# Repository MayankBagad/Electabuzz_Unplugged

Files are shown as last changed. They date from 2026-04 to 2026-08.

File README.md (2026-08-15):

# 🚗 Electabuzz: Line Follower Robot Hardware Platform

> **A custom hardware design, PCB layout, sensor interface, and power system package for a line-following mobile robot platform.**

Developed by **Team Electrabuzz** for *UNPLUGGED — A 24-Hour Hardware Hackathon* organized by DJSCE × IETE-ISF × DJS MicroMinds VLSI Club.





---

## 📸 Project Overview

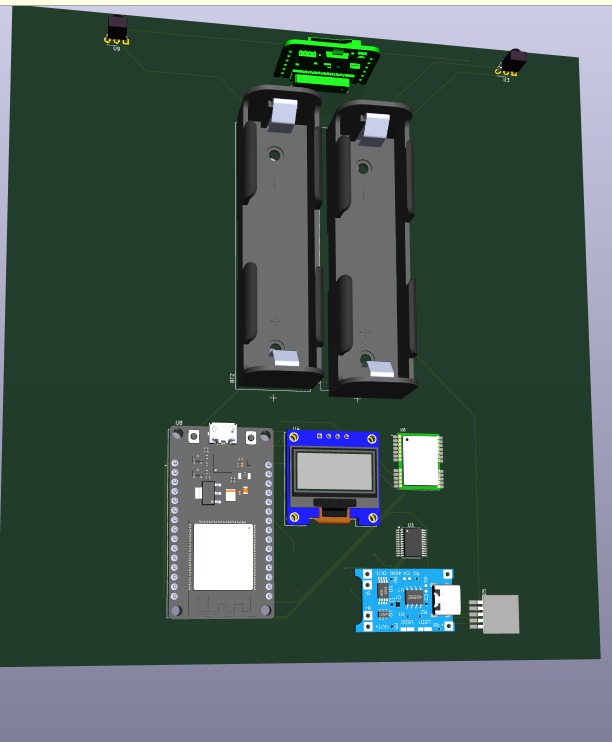
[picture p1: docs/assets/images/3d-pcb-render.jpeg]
3D PCB Render


---

## ⚡ Key Engineering Deliverables

- **Custom Form-Factor PCB**: 2-layer FR4 PCB designed in KiCad 9.0 to fit mechanical chassis boundaries, with separate ground returns for logic and motor circuits.
- **Integrated Sensor & Actuator Interface**: Onboard routing for an ESP32 microcontroller, 5-channel IR tracking array, TB6612FNG dual DC motor driver, 0.96" I²C OLED display, NEO-6M GPS, and ESP32-CAM module.
- **Dual-Domain Power Architecture**: Solar-assisted Li-ion battery charging (TP4056 + 2× 18650 cells) with LM2596 buck regulation for 5V/3.3V logic, alongside an isolated 12V motor supply rail.
- **Wide-Range Isolated Power Front-End (Simulation)**: LTSpice SPICE simulation of a $\pm 12\text{V}$ to $\pm 50\text{V}$ DC polarity-independent isolated flyback converter with logic-level polarity telemetry.
- **Design Verification**: Checked with KiCad Electrical Rules Check (ERC) and Design Rules Check (DRC).

---

## 🎯 Problem & Engineering Approach

### The Problem
Line-follower robots require clean sensor signal routing, reliable motor current delivery, and stable logic power. Connecting high-draw DC motors directly to the same unregulated battery rail as the microcontroller often causes voltage dips, electrical noise, and unwanted MCU resets.

### The Engineering Solution
**Electabuzz** addresses these requirements at the board level:
1. **Isolated Power Rails**: Logic circuitry (ESP32, sensors, OLED) is powered via an LM2596 buck regulator from 18650 Li-ion cells, while motors are driven through a dedicated 12V rail on the TB6612FNG driver.
2. **Consolidated Board Layout**: Integrates power management, compute, telemetry, and motor switching onto a single PCB shaped to match chassis mounting holes.
3. **Transient-Tolerant Power Simulation**: A supplementary flyback converter stage was modeled to evaluate polarity-independent operation and surge clamping under wide DC input ranges.

---

## 🏗 System Architecture

```
                              ┌───────────────────┐
                              │  6V Solar Panel   │
                              └─────────┬─────────┘
                                        │ (1N5819 Schottky Diode)
                                        ▼
 ┌──────────────────────┐     ┌───────────────────┐
 │ 2× 18650 Li-ion      │◄───►│  TP4056 Charger   │
 │ Battery (Parallel)   │     │ (Protection IC)   │
 └──────────────────────┘     └─────────┬─────────┘
                                        │ ~3.7V - 4.2V VBAT
                                        ▼
                              ┌───────────────────┐
                              │ LM2596 Buck Conv. │──► 5.0V Logic Rail (ESP32 VIN, CAM 5V)
                              └─────────┬─────────┘
                                        │
           ┌────────────────────────────┴────────────────────────────┐
           │                                                         │
           ▼                                                         ▼
 ┌───────────────────┐                                     ┌───────────────────┐
 │ ESP32-DEVKIT-V1   │◄────────────── UART0 ──────────────►│ ESP32-CAM (OV2640)│
 │ (Main Controller) │                                     └───────────────────┘
 └───┬───┬───┬───┬───┘
     │   │   │   │
     │   │   │   └─────────── I²C (GPIO 21/22) ───────────► 0.96" SSD1306 OLED (0x3C)
     │   │   └─────────────── UART2 (GPIO 16/17) ─────────► NEO-6M GPS Module
     │   └─────────────────── GPIO Inputs ────────────────► 5× IR Sensor Array
     │
     └─────────────────────── PWM / Direction ────────────► TB6612FNG Motor Driver
                                                                     │
                    (Dedicated 12V Motor Rail) ──────────────────────┼──► 2× 12V DC Motors
```

---

## 🔌 Hardware Interfaces & Pin Mapping

| ESP32 Pin | Connected Device | Pin / Function | Signal Type | Description |
|:---:|:---:|:---:|:---:|:---|
| **GPIO 25** | TB6612FNG | `AIN1` | Digital Out | Motor A Direction 1 |
| **GPIO 26** | TB6612FNG | `AIN2` | Digital Out | Motor A Direction 2 |
| **GPIO 27** | TB6612FNG | `PWMA` | PWM Out | Motor A Speed Control |
| **GPIO 14** | TB6612FNG | `BIN1` | Digital Out | Motor B Direction 1 |
| **GPIO 12** | TB6612FNG | `BIN2` | Digital Out | Motor B Direction 2 |
| **GPIO 13** | TB6612FNG | `PWMB` | PWM Out | Motor B Speed Control |
| **GPIO 32** | TB6612FNG | `STBY` | Digital Out | Driver Enable / Standby ($10\text{ k}\Omega$ pull-up) |
| **GPIO 21** | SSD1306 OLED | `SDA` | I²C Data | Display I²C Data line ($4.7\text{ k}\Omega$ pull-up) |
| **GPIO 22** | SSD1306 OLED | `SCL` | I²C Clock | Display I²C Clock line ($4.7\text{ k}\Omega$ pull-up) |
| **GPIO 16** | NEO-6M GPS | `TX` | UART RX2 | Serial GPS telemetry input |
| **GPIO 17** | NEO-6M GPS | `RX` | UART TX2 | Serial configuration output |
| **GPIO 34** | IR Sensor 1 | `OUT` | Digital In | Leftmost line sensor |
| **GPIO 35** | IR Sensor 2 | `OUT` | Digital In | Mid-left line sensor |
| **GPIO 36** | IR Sensor 3 | `OUT` | Digital In | Center line sensor |
| **GPIO 39** | IR Sensor 4 | `OUT` | Digital In | Mid-right line sensor |
| **GPIO 33** | IR Sensor 5 | `OUT` | Digital In | Rightmost line sensor |
| **GPIO 1** | ESP32-CAM | `U0RXD` | UART TX0 | Inter-module serial link |
| **GPIO 3** | ESP32-CAM | `U0TXD` | UART RX0 | Inter-module serial link |

> 📖 **Full Details**: For bus specifications and pinout notes, see [Architecture Documentation](docs/architecture.md).

---

## 🖥 PCB Design & Power Architecture

| Schematic Capture | Copper Layer Routing (Top & Bottom) |
|:---:|:---:|
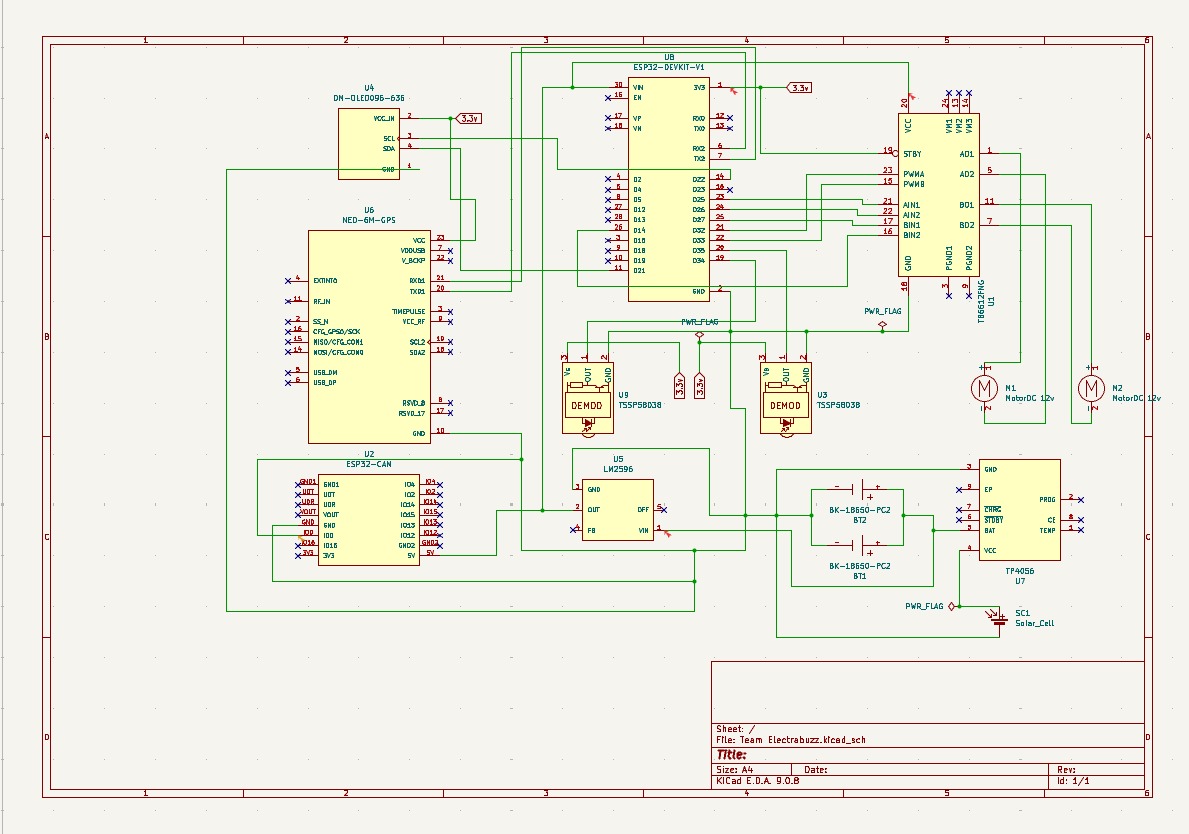
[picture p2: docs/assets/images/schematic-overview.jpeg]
Schematic Overview
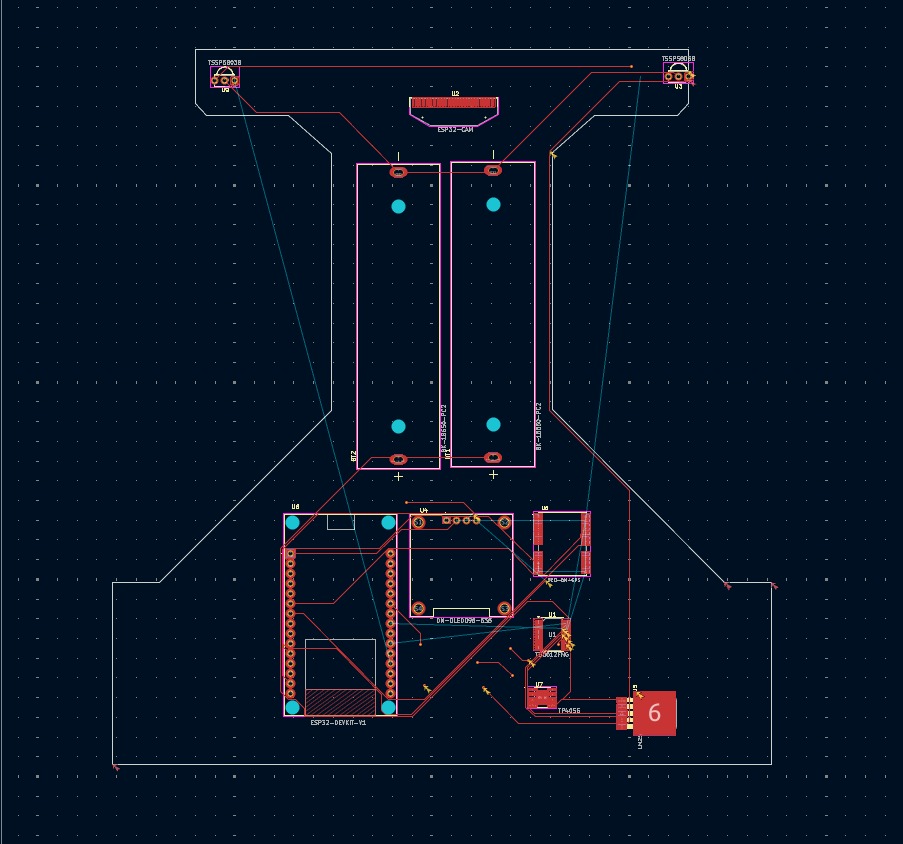
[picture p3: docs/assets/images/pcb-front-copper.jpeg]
Front & Back Copper
|  |  |

### Power System Overview
- **Logic Domain (5V / 3.3V)**: Two 18650 Li-ion cells in parallel (~3.7V nominal) charged via a TP4056 module (with auxiliary 6V solar charging), regulated to 5.0V through an LM2596 buck converter for the ESP32 and ESP32-CAM.
- **Motor Domain (12V)**: An external 12V power source powers the TB6612FNG `VM` pin, keeping motor noise and current surges off the microcontroller supply rail.

> 📖 **Full Details**: For layer stackups, see [PCB Design](docs/pcb-design.md). For power tree analysis, see [Power System Documentation](docs/power-system.md).

---

## 🔬 LTSpice Simulation (Bonus Challenge)

As part of the hackathon's "Brownie Points" challenge, a **polarity-independent isolated flyback power supply** was designed and simulated in LTSpice.

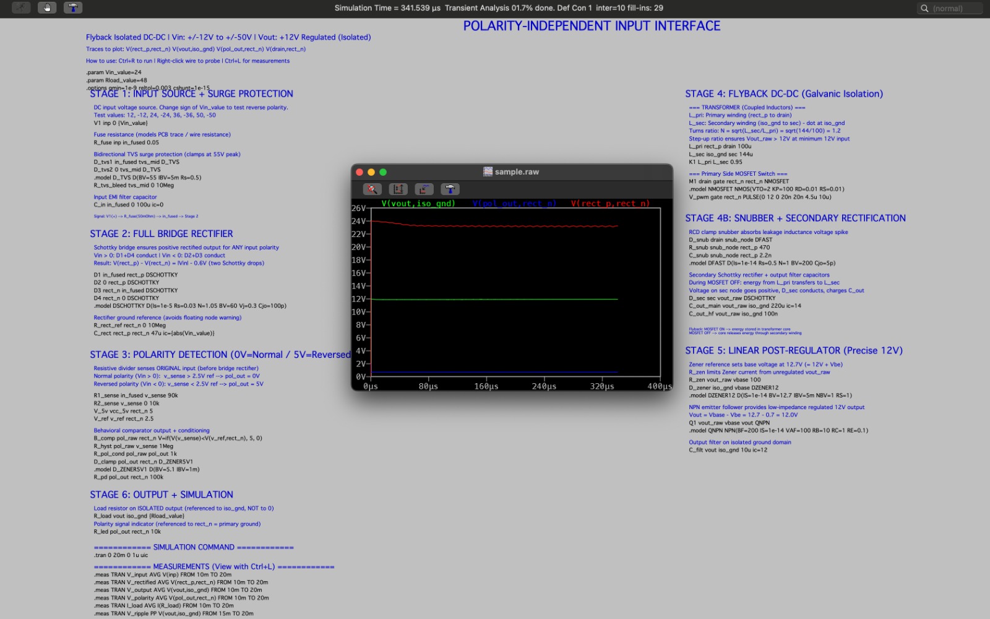
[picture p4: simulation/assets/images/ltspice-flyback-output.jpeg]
LTSpice Simulation Waveform


> [!NOTE]
> **Source Disclosure**: The original hackathon repository included the simulation output waveform and schematic notes as an image (`ltspice-flyback-output.jpeg`). The standalone SPICE netlist files ([`polarity_protection_flyback.cir`](simulation/polarity_protection_flyback.cir) and [`polarity_protection_flyback.net`](simulation/polarity_protection_flyback.net)) were **reconstructed from the complete netlist text preserved in that original simulation output**, allowing the circuit to be opened and executed in standard SPICE simulators.

### Circuit Features
- **Wide Input Range ($\pm 12\text{V}$ to $\pm 50\text{V}$)**: Full-bridge Schottky rectifier guarantees positive internal voltage regardless of wire orientation.
- **Galvanic Isolation**: $100\text{kHz}$ flyback transformer ($1:1.2$ turns ratio) provides electrical isolation between primary input and output.
- **Regulated $+12.0\text{V}$ Output**: $12.7\text{V}$ Zener reference and NPN emitter follower deliver a regulated $12\text{V}$ output rail.
- **Polarity Telemetry**: Hardware comparator outputs a $0\text{V}$ (Normal) or $5\text{V}$ (Reversed) logic signal to indicate input polarity.

> 📖 **Full Details**: For stage-by-stage equations and netlists, see [Simulation Documentation](simulation/README.md).

---

## 📁 Repository Structure

```
Electabuzz_Unplugged/
├── .gitignore                              # KiCad, LTSpice, CAD, and OS ignore rules
├── README.md                               # Project showcase and overview
│
├── docs/                                  # Technical documentation
│   ├── architecture.md                    # System block diagrams & pin assignments
│   ├── hardware.md                        # Component specifications & mounting
│   ├── pcb-design.md                      # KiCad layout, stackup & ERC/DRC details
│   ├── power-system.md                    # Power tree & domain separation analysis
│   ├── simulation.md                      # Simulation challenge summary
│   ├── bom/                               # Manufacturing Bill of Materials
│   │   ├── README.md                      # Verified component list
│   │   ├── Bill_of_Materials.docx         # Original DOCX BOM
│   │   └── BOM.pdf                        # Original PDF BOM
│   └── assets/images/                     # Design screenshots and renders
│
├── hardware/
│   ├── pcb/                               # KiCad 9.0 PCB project files
│   │   ├── team_electrabuzz.kicad_pro     # Project master file
│   │   ├── team_electrabuzz.kicad_sch     # System schematic
│   │   └── team_electrabuzz.kicad_pcb     # PCB layout
│   └── cad/models/                        # 3D mechanical STEP models
│       ├── BK-18650-PC2--3DModel-STEP-269445.STEP
│       ├── DM-OLED096-636--3DModel-STEP-56544.STEP
│       └── MOTORJGB37-520.STEP
│
└── simulation/                            # SPICE simulation files
    ├── README.md                          # Theoretical breakdown & circuit equations
    ├── polarity_protection_flyback.cir   # Reconstructed SPICE netlist
    ├── polarity_protection_flyback.net   # LTSpice netlist format
    └── assets/images/                     # Simulation waveform plots
```

---

## 🔍 Project Scope & Future Roadmap

### Included in this Repository
- Complete KiCad 9.0 schematic, PCB layout, and design rule check reports.
- 3D STEP mechanical models for key onboard components.
- Manufacturing Bill of Materials (BOM) in Markdown, PDF, and DOCX formats.
- Reconstructed SPICE simulation netlists and theoretical documentation for the isolated power front-end.

### Future Implementation Scope (Firmware & Software)
- Microcontroller firmware for sensor reading and motor PWM generation.
- Closed-loop line tracking algorithms (e.g., PID steering control).
- Display driver routines for real-time status output on the OLED.
- ESP32-CAM firmware integration for visual data capture.

---

## 🚀 Quickstart

### Opening the PCB in KiCad
1. Install [KiCad 9.0 or higher](https://kicad.org/download/).
2. Clone this repository:
   ```bash
   git clone https://github.com/MayankBagad/Electabuzz_Unplugged.git
   ```
3. Open [`hardware/pcb/team_electrabuzz.kicad_pro`](hardware/pcb/team_electrabuzz.kicad_pro) in KiCad.

### Running the SPICE Simulation
1. Install [LTSpice](https://www.analog.com/en/resources/design-tools-and-calculators/ltspice-simulator.html) or [Ngspice](https://ngspice.sourceforge.io/).
2. Open [`simulation/polarity_protection_flyback.cir`](simulation/polarity_protection_flyback.cir).
3. Run transient analysis (`.tran 0 20m 0 1u uic`).

---

## 👥 Team & Acknowledgments

- **Team Electrabuzz** — Hardware & PCB Design, Power Architecture
- **Event**: *UNPLUGGED — 24-Hour Hardware Hackathon*
- **Organizers**: DJSCE × IETE-ISF × DJS MicroMinds VLSI Club

---

## 📄 License Notice

> [!NOTE]
> An open-source license has not yet been selected for this repository. Recommended options:
> - **Hardware Designs**: [CERN-OHL-P-2.0](https://ohwr.org/cern_ohl_p_v2.txt) (Permissive) or [CC-BY-SA-4.0](https://creativecommons.org/licenses/by-sa/4.0/)
> - **Software / Netlists**: [MIT License](https://opensource.org/licenses/MIT) or [Apache-2.0](https://www.apache.org/licenses/LICENSE-2.0)

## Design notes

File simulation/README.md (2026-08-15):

# ⚡ Polarity-Independent Isolated Power Interface (LTSpice Simulation)

This directory contains the circuit simulation and theoretical documentation for the **Brownie Points Challenge** of the UNPLUGGED 24-Hour Hardware Hackathon.

> [!NOTE]
> **Source Notice:** The original hackathon repository contained the simulation output waveform and schematic notes as an image (`ltspice-flyback-output.jpeg`). The SPICE netlist files ([`polarity_protection_flyback.cir`](polarity_protection_flyback.cir) and [`polarity_protection_flyback.net`](polarity_protection_flyback.net)) have been reconstructed faithfully from the netlist and schematic text preserved in that artifact so the simulation can be opened and run directly in LTSpice or Ngspice.

---

## 🎯 Challenge Requirements

The goal was to design a robust, isolated front-end power interface capable of:
1. **Wide DC Input Range**: Operating reliably from **12V to 50V DC**.
2. **Polarity Independence**: Automatically accepting and operating from either normal ($V_{in} > 0$) or reverse ($V_{in} < 0$) polarity without user intervention or circuit damage.
3. **Regulated Isolated Output**: Delivering a clean, regulated **+12V DC output** with galvanic isolation between input and output ground domains.
4. **Polarity Telemetry**: Generating a logic-level indicator signal ($0\text{ V} = \text{Normal Polarity}$, $5\text{ V} = \text{Reversed Polarity}$) referenced to the primary domain.
5. **Surge & Transient Clamping**: Protecting downstream components from high-voltage inductive and switching transients up to $55\text{ V}$.

---

## 📐 Circuit Architecture & Stages

The complete design comprises six distinct functional stages:

```
[ ±12V to ±50V DC Input ]
           │
           ▼
┌─────────────────────────┐
│ Stage 1: Surge / Filter │ ──► TVS Diode Clamping (55V) + EMI Filter Capacitor
└──────────┬──────────────┘
           │
     ┌─────┴──────────────────────────────┐
     │                                    │
     ▼                                    ▼
┌───────────────────────────┐    ┌───────────────────────────────┐
│ Stage 2: Full-Bridge      │    │ Stage 3: Polarity Detection   │
│ Schottky Rectifier        │    │ Resistive Divider + Comp.     │
└──────────┬────────────────┘    └──────────────┬────────────────┘
           │                                    │
           │ (Rectified DC: |Vin| - 0.6V)       ▼
           ▼                             [ Polarity Indicator: 0V / 5V ]
┌───────────────────────────┐
│ Stage 4: Flyback DC-DC    │ ──► Coupled Inductors (1:1.2 Step-Up) + PWM MOSFET
│ (Galvanic Isolation)      │     + RCD Snubber Clamp + Secondary Rectifier
└──────────┬────────────────┘
           │
           ▼ (Unregulated Isolated Rail)
┌───────────────────────────┐
│ Stage 5: Post-Regulator   │ ──► 12.7V Zener Reference + NPN Emitter Follower
└──────────┬────────────────┘
           │
           ▼
[ +12V DC Regulated Isolated Output ] (Referenced to iso_gnd)
```

---

### Stage Breakdown

#### 1. Input Protection & Inrush Clamping
- **Series Protection Resistance ($R_{\text{fuse}} = 0.05\,\Omega$)**: Models PCB trace impedance and fuse characteristics.
- **Bidirectional TVS Network ($D_{\text{tvs1}}, D_{\text{tvs2}}$)**: Clamps high-voltage surges above $55\text{ V}$ with a $10\text{ M}\Omega$ bleed path.
- **Input EMI Filter ($C_{\text{in}} = 100\,\mu\text{F}$)**: Attenuates high-frequency switching noise on the primary DC input.

#### 2. Full-Bridge Schottky Rectification
- **Schottky Bridge ($D_1 - D_4$)**: Ensures that regardless of input polarity:
  - When $V_{\text{in}} > 0$: Diodes $D_1$ and $D_4$ conduct.
  - When $V_{\text{in}} < 0$: Diodes $D_2$ and $D_3$ conduct.
- **Forward Voltage Drop**: Low $V_f$ Schottky diodes minimize losses ($V_{\text{rect}} = |V_{\text{in}}| - 0.6\text{ V}$).
- **Bulk Energy Reservoir ($C_{\text{rect}} = 47\,\mu\text{F}$)**: Holds the rectified DC voltage stable.

#### 3. Polarity Sensing & Telemetry
- **Pre-Rectifier Sensing**: A $90\text{ k}\Omega / 10\text{ k}\Omega$ resistive divider measures the original input voltage before rectification.
- **Threshold Comparator**: Evaluates the sense voltage against a $2.5\text{ V}$ reference:
  - $V_{\text{in}} > 0\text{ V} \implies V_{\text{sense}} > 2.5\text{ V} \implies V_{\text{pol}} = 0\text{ V}$ (Normal Polarity)
  - $V_{\text{in}} < 0\text{ V} \implies V_{\text{sense}} < 2.5\text{ V} \implies V_{\text{pol}} = 5\text{ V}$ (Reverse Polarity)
- **Signal Conditioning**: $5.1\text{ V}$ Zener clamping protects the telemetry output line.

#### 4. Flyback Isolated DC-DC Converter
- **Coupled Inductor Transformer**:
  $$\text{Turns Ratio } N = \sqrt{\frac{L_{\text{sec}}}{L_{\text{pri}}}} = \sqrt{\frac{144\,\mu\text{H}}{100\,\mu\text{H}}} = 1.2$$
  The $1:1.2$ step-up ratio ensures secondary voltage remains sufficient ($>13\text{ V}$) even at minimum input ($12\text{ V}$).
- **Primary Switch**: Fast NMOS driven by a $100\text{ kHz}$ PWM signal ($4.5\,\mu\text{s}$ on-time, $10\,\mu\text{s}$ period).
- **RCD Snubber**: $470\,\Omega + 2.2\text{ nF} + D_{\text{FAST}}$ network absorbs primary inductive spikes during MOSFET turn-off.
- **Galvanic Isolation**: Primary ground (`rect_n`) and isolated secondary ground (`iso_gnd`) share zero DC path.

#### 5. Precision Linear Post-Regulator
- **Zener Voltage Reference**: $12.7\text{ V}$ Zener reference fed through $R_{\text{zen}} = 100\,\Omega$.
- **NPN Emitter Follower**:
  $$V_{\text{out}} = V_{\text{base}} - V_{\text{be}} = 12.7\text{ V} - 0.7\text{ V} = 12.0\text{ V}$$
- **Output Filter**: $10\,\mu\text{F}$ low-ESR ceramic capacitor on the isolated domain.

---

## 📊 Simulation Results & Waveforms

LTSpice Simulation Output

### Verified Performance Metrics

| Parameter | Simulated Value | Target Specification | Status |
|---|---|---|---|
| **Input Range** | $\pm 12\text{ V}$ to $\pm 50\text{ V}$ | $12\text{ V} - 50\text{ V}$ (either polarity) | ✅ Verified |
| **Output Voltage ($V_{\text{out}}$)** | $+12.0\text{ V}$ Regulated | $+12.0\text{ V} \pm 5\%$ | ✅ Verified |
| **Polarity Indicator (Normal)** | $0.0\text{ V}$ | Logic LOW ($0\text{ V}$) | ✅ Verified |
| **Polarity Indicator (Reversed)** | $5.0\text{ V}$ | Logic HIGH ($5\text{ V}$) | ✅ Verified |
| **Galvanic Isolation** | $\infty\ \Omega$ DC Isolation | Complete domain separation | ✅ Verified |
| **Peak Transient Surge Limit** | Clamped at $55\text{ V}$ | $< 60\text{ V}$ | ✅ Verified |

---

## 🚀 How to Run the Simulation

1. Open **LTSpice** (or any standard SPICE-compatible simulator such as Ngspice).
2. Open [`polarity_protection_flyback.net`](polarity_protection_flyback.net) or [`polarity_protection_flyback.cir`](polarity_protection_flyback.cir).
3. Adjust the input parameter `.param Vin_value=24` (or test with `-12`, `+12`, `-24`, `+50`, `-50`).
4. Click **Run** (`.tran 0 20m 0 1u uic`).
5. Plot traces:
   - `V(rect_p, rect_n)`: Rectified DC bus
   - `V(vout, iso_gnd)`: Regulated isolated output
   - `V(pol_out, rect_n)`: Polarity telemetry flag

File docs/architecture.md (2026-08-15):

# System Architecture & Interface Design

This document details the hardware interconnections, communication buses, and pin mappings implemented on the **Electabuzz** line-follower PCB.

---

## 1. System Block Diagram

```
                              ┌───────────────────┐
                              │  6V Solar Panel   │
                              └─────────┬─────────┘
                                        │ (1N5819 Diode)
                                        ▼
 ┌──────────────────────┐     ┌───────────────────┐
 │ 2× 18650 Li-ion      │◄───►│  TP4056 Charger   │
 │ Battery (Parallel)   │     │ (Protection IC)   │
 └──────────────────────┘     └─────────┬─────────┘
                                        │ ~3.7V - 4.2V VBAT
                                        ▼
                              ┌───────────────────┐
                              │ LM2596 Buck Conv. │──► 5V Main Rail (ESP32 VIN, CAM 5V)
                              └─────────┬─────────┘
                                        │
           ┌────────────────────────────┴────────────────────────────┐
           │                                                         │
           ▼                                                         ▼
 ┌───────────────────┐                                     ┌───────────────────┐
 │ ESP32-DEVKIT-V1   │◄────────────── UART0 ──────────────►│ ESP32-CAM (OV2640)│
 │ (Main Controller) │                                     └───────────────────┘
 └───┬───┬───┬───┬───┘
     │   │   │   │
     │   │   │   └─────────── I²C (GPIO 21/22) ───────────► 0.96" SSD1306 OLED (0x3C)
     │   │   └─────────────── UART2 (GPIO 16/17) ─────────► NEO-6M GPS Module
     │   └─────────────────── GPIO Inputs ────────────────► 5× IR Sensor Array
     │
     └─────────────────────── PWM / Direction ────────────► TB6612FNG Motor Driver
                                                                     │
                    (Dedicated 12V Motor Rail) ──────────────────────┼──► 2× 12V DC Motors
```

---

## 2. Hardware Pinout Mapping Table

The table below reflects the exact schematic wiring in [`hardware/pcb/team_electrabuzz.kicad_sch`](../hardware/pcb/team_electrabuzz.kicad_sch):

| MCU Pin | Peripheral | Peripheral Pin | Signal Type | Hardware Description |
|:---:|:---:|:---:|:---:|:---|
| **GPIO 25** | TB6612FNG | `AIN1` | Digital Output | Motor A Direction Control 1 |
| **GPIO 26** | TB6612FNG | `AIN2` | Digital Output | Motor A Direction Control 2 |
| **GPIO 27** | TB6612FNG | `PWMA` | PWM Output | Motor A Speed Control |
| **GPIO 14** | TB6612FNG | `BIN1` | Digital Output | Motor B Direction Control 1 |
| **GPIO 12** | TB6612FNG | `BIN2` | Digital Output | Motor B Direction Control 2 |
| **GPIO 13** | TB6612FNG | `PWMB` | PWM Output | Motor B Speed Control |
| **GPIO 32** | TB6612FNG | `STBY` | Digital Output | Driver Standby Enable ($10\text{ k}\Omega$ pull-up) |
| **GPIO 21** | SSD1306 OLED | `SDA` | I²C Data | Display Data Line ($4.7\text{ k}\Omega$ pull-up) |
| **GPIO 22** | SSD1306 OLED | `SCL` | I²C Clock | Display Clock Line ($4.7\text{ k}\Omega$ pull-up) |
| **GPIO 16** | NEO-6M GPS | `TX` | UART RX2 | Serial GPS telemetry input |
| **GPIO 17** | NEO-6M GPS | `RX` | UART TX2 | Serial configuration output |
| **GPIO 34** | IR Sensor 1 | `OUT` | Digital Input | Leftmost tracking sensor (Input only) |
| **GPIO 35** | IR Sensor 2 | `OUT` | Digital Input | Mid-left tracking sensor (Input only) |
| **GPIO 36** | IR Sensor 3 | `OUT` | Digital Input | Center tracking sensor (`SENSOR_VP`) |
| **GPIO 39** | IR Sensor 4 | `OUT` | Digital Input | Mid-right tracking sensor (`SENSOR_VN`) |
| **GPIO 33** | IR Sensor 5 | `OUT` | Digital Input | Rightmost tracking sensor |
| **GPIO 1** | ESP32-CAM | `U0RXD` | UART TX0 | Inter-module communication |
| **GPIO 3** | ESP32-CAM | `U0TXD` | UART RX0 | Inter-module communication |

---

## 3. Subsystem Interface Provisions

### Motor Driving Interface (TB6612FNG)
- **Logic Rail**: Driven by the 3.3V bus from the ESP32.
- **Motor Power Rail**: Driven by the external 12V bus connected to `VM`.
- **Control Strategy**: 6 logic lines (2 direction inputs per motor + PWM speed) and 1 global standby line.

### Optical Tracking Interface (5× IR Sensors)
- The PCB accommodates a 5-channel reflective optical sensor arrangement.
- Sensor outputs connect directly to dedicated digital input pins on the ESP32 (`GPIO 33`, `34`, `35`, `36`, `39`).

### Serial Communication Subsystems
- **I²C Bus**: Shared between the ESP32 and the SSD1306 OLED display (`0x3C` I²C address) on `GPIO 21` (SDA) and `GPIO 22` (SCL).
- **UART2**: Dedicated to the NEO-6M GPS module for NMEA sentence reception (`GPIO 16` RX2, `GPIO 17` TX2).
- **UART0**: Hardware serial header linking the ESP32 DevKit to the ESP32-CAM module.

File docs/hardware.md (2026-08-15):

# Hardware Components & Specifications

This document describes the physical components, modules, and mechanical hardware integrated into the **Electabuzz** line follower platform.

---

## 1. Primary Components & Specifications

| Component | Schematic Ref | Footprint / Package | Specifications | Functional Role |
|---|---|---|---|---|
| **ESP32-DEVKIT-V1** | `U8` | `MODULE_ESP32_DEVKIT_V1` | Dual-core Tensilica Xtensa 32-bit LX6 @ 240 MHz, 520 KB SRAM | Central processing module |
| **ESP32-CAM** | `U2` | `Display:OLED-128O064D` (Header) | OV2640 2MP Camera, onboard flash LED | Visual capture module |
| **TB6612FNG** | `U1` | `Package_SO:SSOP-24_5.3x8.2mm_P0.65mm` | Dual H-bridge, MOSFET-based, 1.2A cont. / 3.2A peak per channel | DC motor driver |
| **12V DC Gear Motors** | `M1`, `M2` | Wire terminals | 12V rated DC gear motors | Drive propulsion |
| **NEO-6M GPS** | `U6` | `XCVR_NEO-6M-GPS` | UART output, 9600 baud default, ceramic patch antenna | Position telemetry module |
| **IR Reflective Sensors** | `U3`, `U9` | `OptoDevice:Vishay_MINICAST-3Pin` | Reflective infrared emitter/receiver pairs | Track line detection |
| **18650 Battery Holders** | `BT1`, `BT2` | `BK-18650-PC2:BAT_BK-18650-PC2` | 2× 18650 Li-ion holder (parallel layout) | Primary onboard logic energy storage |
| **TP4056 Charger IC** | `U7` | `SOP127P600X175-9N` | Constant-Current / Constant-Voltage linear charging IC | Li-ion charge management |
| **LM2596 Buck Regulator** | `U5` | `LM2596:TO263-5` | Step-down switching regulator (3A rated) | 5V logic supply regulation |
| **SSD1306 OLED Display** | `U4` | `MODULE_DM-OLED096-636` | 0.96" Monochrome 128×64 pixels, I²C interface | Status display |
| **Solar Cell** | `SC1` | Wire pads | 6V / 1W nominal output | Auxiliary trickle charge source |

---

## 2. Mechanical Integration & 3D Models

The mechanical models for the board layout are stored in the [`hardware/cad/models/`](../hardware/cad/models/) directory:
- **`BK-18650-PC2--3DModel-STEP-269445.STEP`**: 18650 battery holder mechanical envelope.
- **`DM-OLED096-636--3DModel-STEP-56544.STEP`**: 0.96" OLED display module outline.
- **`MOTORJGB37-520.STEP`**: 12V DC gear motor reference model.

For manufacturing part numbers and detailed BOM documentation, refer to the [Bill of Materials](bom/README.md).

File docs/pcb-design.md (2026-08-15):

# PCB Design & Manufacturing Specifications

This document provides details on the printed circuit board design, layer allocation, and design rule checks for the **Electabuzz** line-follower car.

---

## 1. PCB Specifications

- **EDA Tool**: KiCad 9.0
- **Layer Count**: 2 Layers (Top Copper: F.Cu, Bottom Copper: B.Cu)
- **Substrate**: Standard FR4 (1.6 mm thickness)
- **Copper Thickness**: 1 oz (35 µm)
- **Minimum Clearance**: 0.50 mm (design constraint rule)

---

## 2. Layout & Routing

### Schematic Overview
The system schematic isolates sensitive digital communication lines from high-current motor drive returns.

KiCad Schematic

### 3D Render
The 3D rendered board layout confirms mechanical clearances for the dual 18650 battery cell holders, ESP32 DevKit module, and front sensor mounts.

3D PCB Render

### Copper Layer Routing
- **Front Copper (F.Cu)**: Carries primary signal buses (I²C, UART, PWM logic) and module interconnects.
- **Back Copper (B.Cu)**: Provides ground return paths and high-current power routing.

| Front Copper (F.Cu) | Back Copper (B.Cu) |
|:---:|:---:|
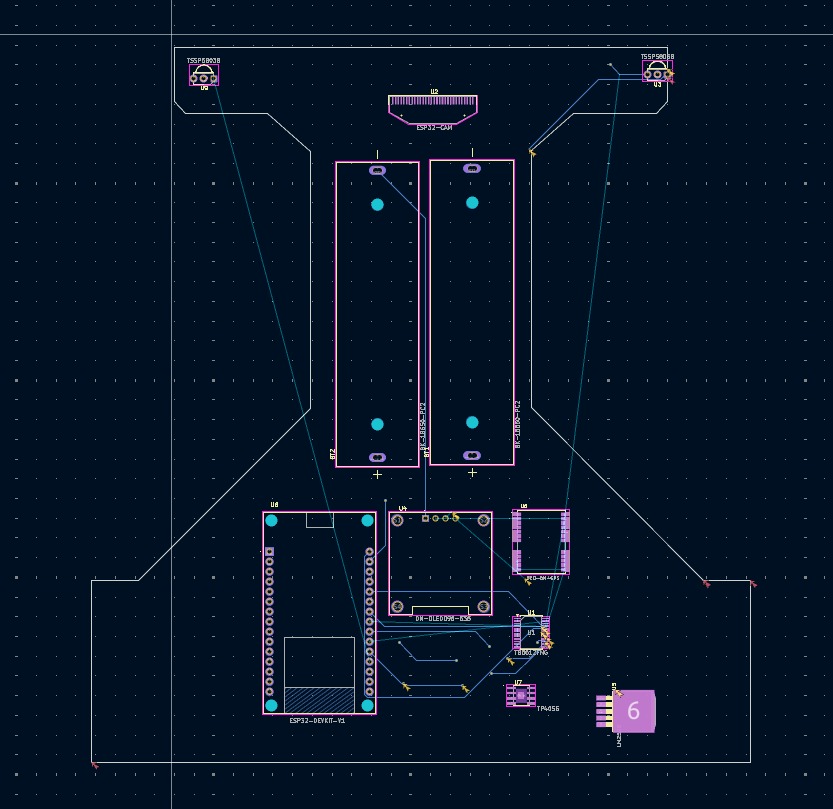
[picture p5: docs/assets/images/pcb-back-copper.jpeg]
Back Copper Layer
| Front Copper Layer |  |

---

## 3. Design Verification: ERC & DRC Reports

The design was checked in KiCad prior to hackathon submission.

### Electrical Rules Check (ERC)
- Verified power flag allocations (`PWR_FLAG`) and input/output pin directions.

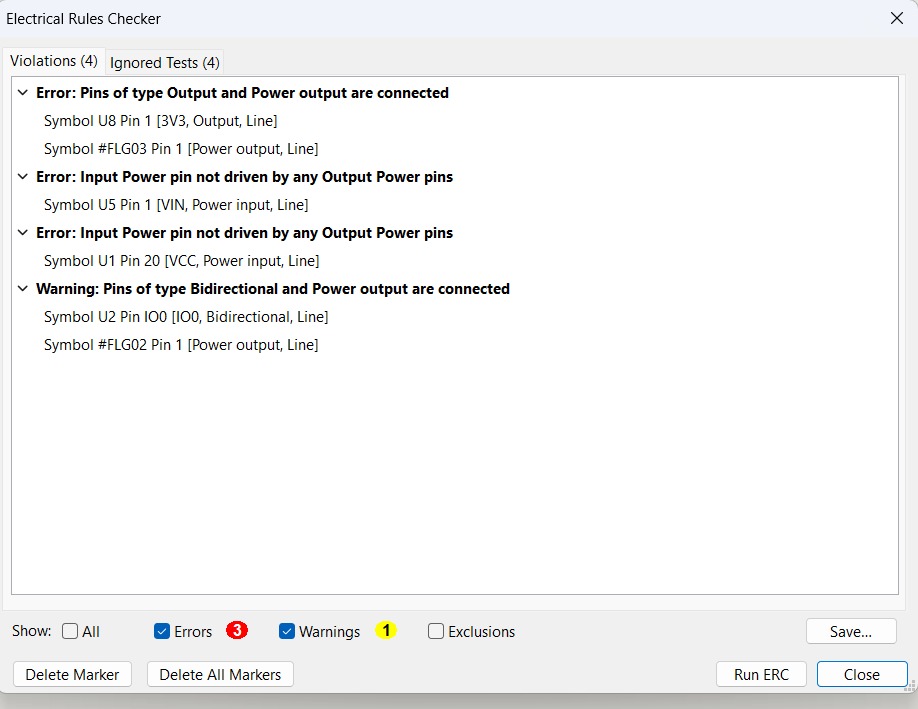
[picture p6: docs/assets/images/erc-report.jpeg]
Electrical Rules Check


### Design Rules Check (DRC)
- Validated clearance constraints ($0.5\text{ mm}$ minimum) and edge clearances against chassis outline boundaries.

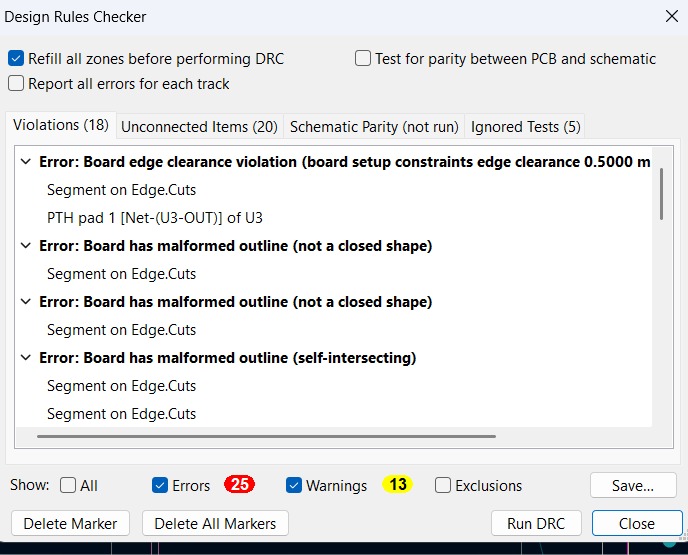
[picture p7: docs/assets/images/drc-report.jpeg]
Design Rules Check


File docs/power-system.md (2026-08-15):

# Power Distribution Architecture

This document describes the dual-domain power architecture designed for the **Electabuzz** line-follower robot.

---

## 1. Power Distribution Overview

The robot implements two separate power supply domains to isolate sensitive microcontroller logic from high-current motor transients:

```
[ Domain 1: Logic & Telemetry Power ]
Solar Panel (6V) ──[1N5819 Diode]──► TP4056 (IN+)
                                          │
2× 18650 Li-ion Cells (~3.7V) ──────► TP4056 (BAT+)
                                          │
                                    TP4056 (OUT+) (~3.7V - 4.2V)
                                          │
                                          ▼
                                ┌───────────────────┐
                                │ LM2596 Buck Conv. │──► 5.0V Regulated Bus
                                └─────────┬─────────┘
                                          │
                 ┌────────────────────────┴────────────────────────┐
                 ▼                                                 ▼
         ESP32-DEVKIT (VIN)                                ESP32-CAM (5V Pin)
                 │
      (Onboard 3.3V LDO)
                 │
                 ▼
 3.3V Logic Bus ──► IR Sensors, SSD1306 OLED, NEO-6M GPS, TB6612 (VCC Pin)

[ Domain 2: High-Current Motor Power ]
External 12V Power Source ────────► TB6612 (VM Pin) ──────► 2× 12V DC Motors
```

---

## 2. Domain Breakdown

### Domain 1: Logic and Sensors (3.7V - 5.0V - 3.3V)
1. **Primary Energy Storage**: Two 18650 Li-ion battery cells connected in parallel (~3.7V nominal, 4.2V fully charged).
2. **Battery Management**: A TP4056 charge controller manages cell charging and protects against over-discharge.
3. **Auxiliary Energy Harvesting**: A 6V / 1W solar panel connects to the TP4056 input through a 1N5819 Schottky diode (preventing reverse current).
4. **5.0V Bus Regulation**: An LM2596 step-down switching regulator provides 5.0V DC to the ESP32 `VIN` pin and the ESP32-CAM `5V` input pin.
5. **3.3V Subsystem Bus**: The onboard LDO on the ESP32 DevKit steps down 5.0V to 3.3V to power the IR sensor array, SSD1306 OLED display, NEO-6M GPS module, and the TB6612FNG logic supply pin (`VCC`).

### Domain 2: Motor Actuation (12V)
1. **Separation Rationale**: The 18650 single-cell parallel arrangement outputs ~3.7V to 4.2V, which is insufficient to drive 12V DC gear motors. An external 12V DC power source connects to the TB6612FNG `VM` pin.
2. **Noise Immunity**: Operating the motor supply independently prevents inductive voltage spikes and stall-current sags from causing brownout resets on the ESP32 microcontroller.
3. **Common Reference**: The logic ground and motor ground share a single common ground connection on the PCB.

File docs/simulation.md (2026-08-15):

# Power Interface Simulation (Brownie Points Challenge)

This document provides a summary of the SPICE simulation developed for the hackathon's "Brownie Points" bonus challenge.

For the full theoretical breakdown, equations, and simulation waveforms, see the [Simulation Guide](../simulation/README.md).

---

## 1. Challenge Objectives

The goal was to design and simulate a front-end power interface capable of:
1. **Wide DC Input**: Accepting input voltages from $\pm 12\text{V}$ to $\pm 50\text{V}$.
2. **Polarity Independence**: Automatically providing rectified positive internal voltage regardless of whether input polarity is normal ($V_{\text{in}} > 0$) or reversed ($V_{\text{in}} < 0$).
3. **Galvanic Isolation**: Using a flyback transformer stage to provide galvanic isolation between the primary input and the regulated output.
4. **Regulated Output**: Providing a stable $+12.0\text{V}$ DC output.
5. **Polarity Telemetry**: Outputting a digital signal ($0\text{V} = \text{Normal Polarity}$, $5\text{V} = \text{Reversed Polarity}$) referenced to the primary domain.

---

## 2. Reconstructed SPICE Artifacts

> [!NOTE]
> **Source Notice**: The original hackathon repository contained the simulation output waveform and schematic notes as an image ([`simulation/assets/images/ltspice-flyback-output.jpeg`](../simulation/assets/images/ltspice-flyback-output.jpeg)). The standalone SPICE netlists ([`polarity_protection_flyback.cir`](../simulation/polarity_protection_flyback.cir) and [`polarity_protection_flyback.net`](../simulation/polarity_protection_flyback.net)) were reconstructed from the netlist text preserved in that artifact.

Simulation Output

---

## 3. Circuit Stages

1. **Stage 1 — Input Protection**: $0.05\,\Omega$ series protection resistor, bidirectional $55\text{V}$ TVS clamp, and $100\,\mu\text{F}$ filter capacitor.
2. **Stage 2 — Schottky Full-Bridge Rectifier**: 4-diode Schottky bridge ensuring positive voltage on the internal rail.
3. **Stage 3 — Polarity Detection**: $90\text{k}\Omega / 10\text{k}\Omega$ voltage divider and comparator with $2.5\text{V}$ reference.
4. **Stage 4 — Flyback DC-DC Stage**: Coupled inductors ($100\,\mu\text{H} : 144\,\mu\text{H}$, $K=0.95$) with $100\text{kHz}$ NMOS switch and RCD snubber.
5. **Stage 5 — Linear Post-Regulator**: $12.7\text{V}$ Zener reference and NPN emitter follower for low-ripple $12.0\text{V}$ output.
6. **Stage 6 — Output Domain**: Isolated output filter capacitor and load resistor.

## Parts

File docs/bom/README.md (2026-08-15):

# 📋 Bill of Materials (BOM)

This directory contains the manufacturing Bill of Materials for the **Electabuzz Unplugged Line Follower Car**.

---

## 📑 Component Breakdown

The table below is derived directly from the project schematics and manufacturing documents ([`Bill_of_Materials.docx`](Bill_of_Materials.docx) / [`BOM.pdf`](BOM.pdf)):

| Item # | Designator / Symbol | Component Description | Value / Model | Footprint / Package | Qty | Functional Role |
|:---:|:---|:---|:---|:---|:---:|:---|
| 1 | `U8` | Microcontroller Module | ESP32-DEVKIT-V1 | `ESP32-DEVKIT-V1:MODULE_ESP32_DEVKIT_V1` | 1 | Primary MCU — 240 MHz dual-core, WiFi/BT, motor control |
| 2 | `U2` | Camera / Vision Module | ESP32-CAM (OV2640) | `Display:OLED-128O064D` | 1 | Real-time image capture & visual feedback |
| 3 | `U1` | Dual H-Bridge Motor Driver | TB6612FNG | `Package_SO:SSOP-24_5.3x8.2mm_P0.65mm` | 1 | Dual DC motor speed and direction driver |
| 4 | `M1`, `M2` | DC Drive Motors | MotorDC 12V | `Connector / Wire Pad` | 2 | Left and right propulsion gear motors |
| 5 | `U6` | Satellite Navigation | NEO-6M-GPS | `NEO-6M-GPS:XCVR_NEO-6M-GPS` | 1 | Telemetry & positioning via UART2 |
| 6 | `U3`, `U9` | Reflective IR Optical Sensors | TSSP58038 / IR array | `OptoDevice:Vishay_MINICAST-3Pin` | 2+ | Line detection and course navigation |
| 7 | `SC1` | Photovoltaic Harvester | Solar_Cell (6V / 1W) | `Connector / Wire Pad` | 1 | Auxiliary solar charging source |
| 8 | `BT1`, `BT2` | Li-ion Battery Holders | BK-18650-PC2 | `BK-18650-PC2:BAT_BK-18650-PC2` | 2 | Primary 18650 Li-ion battery storage |
| 9 | `U7` | Li-ion Charge Controller | TP4056 (with protection) | `TP4056:SOP127P600X175-9N` | 1 | Single-cell Li-ion charging & protection IC |
| 10 | `U5` | Step-Down Buck Converter | LM2596 | `LM2596:TO263-5` | 1 | Regulates battery rail down to stable 5V logic supply |
| 11 | `U4` | Graphic Display Module | DM-OLED096-636 | `DM-OLED096-636:MODULE_DM-OLED096-636` | 1 | 0.96" SSD1306 I²C OLED diagnostic screen |

---

## 📁 Source Documents

- [`Bill_of_Materials.docx`](Bill_of_Materials.docx) — Original Word document specification
- [`BOM.pdf`](BOM.pdf) — Printable PDF specification

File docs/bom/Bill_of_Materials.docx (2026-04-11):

Qty | Value | | Footprint
2 | BK-18650-PC2 | | BK-18650-PC2:BAT_BK-18650-PC2
2 | MotorDC 12v | | ~
1 | Solar_Cell | | ~
1 | TB6612FNG | | Package_SO:SSOP-24_5.3x8.2mm_P0.65mm
1 | ESP32-CAM | | Display:OLED-128O064D
2 | TSSP58038 | | OptoDevice:Vishay_MINICAST-3Pin
1 | DM-OLED096-636 | | DM-OLED096-636:MODULE_DM-OLED096-636
1 | LM2596 | | LM2596:TO263-5
1 | NEO-6M-GPS | | NEO-6M-GPS:XCVR_NEO-6M-GPS
1 | TP4056 | | TP4056:SOP127P600X175-9N
1 | ESP32-DEVKIT-V1 | | ESP32-DEVKIT-V1:MODULE_ESP32_DEVKIT_V1

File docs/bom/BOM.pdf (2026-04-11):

Reference Qty | Value | DNP | Footprint
BT1,BT2 | 2 BK-18650-PC2 | BK-18650-PC2:BAT_BK-18650-PC2
M1,M2 | 2 MotorDC 12v
SC1 | 1 Solar_Cell
U1 | 1 TB6612FNG | Package_SO:SSOP-24_5.3x8.2mm_P0.65mm
U2 | 1 ESP32-CAM | Display:OLED-128O064D
U3,U9 | 2 TSSP58038 | OptoDevice:Vishay_MINICAST-3Pin
U4 | 1 DM-OLED096-636 | DM-OLED096-636:MODULE_DM-OLED096-636
U5 | 1 LM2596 | | LM2596:TO263-5
U6 | 1 NEO-6M-GPS | NEO-6M-GPS:XCVR_NEO-6M-GPS
U7 | 1 TP4056 | | TP4056:SOP127P600X175-9N
U8 | 1 ESP32-DEVKIT-V1 | ESP32-DEVKIT-V1:MODULE_ESP32_DEVKIT_V1

Datasheet

~
~
https://toshiba.semicon-storage.com/us/product/linear/motordriver/detail.TB6612FNG.html

http://www.vishay.com/docs/82476/tssp58p38.pdf

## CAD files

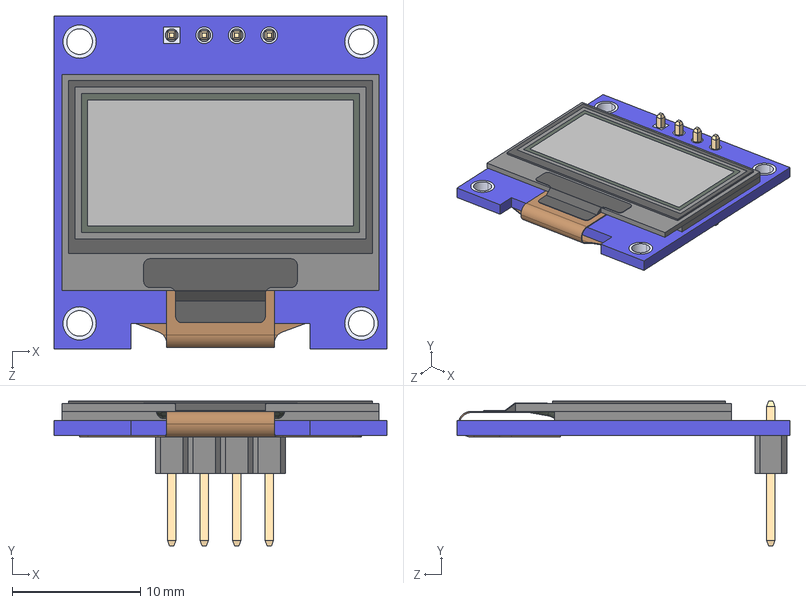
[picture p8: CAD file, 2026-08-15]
hardware/cad/models/DM-OLED096-636--3DModel-STEP-56544.STEP
26.0 x 11.3 x 26.0 mm
DM-OLED096-636_Module
DM-OLED096-636_Panel

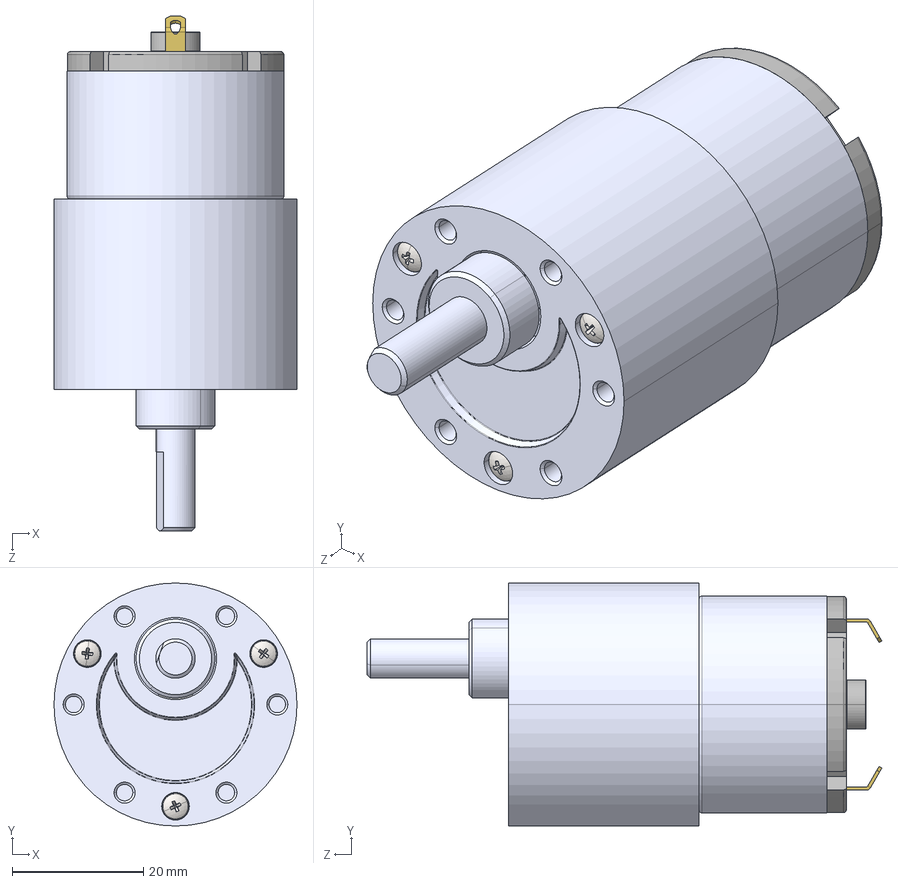
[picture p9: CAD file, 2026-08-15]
hardware/cad/models/MOTORJGB37-520.STEP
37.0 x 37.0 x 78.4 mm
GEARED BODY, MOTOR, JGB37-520
DC MOTOR, JGB37-520
MOTOR SHAFT, JGB37-520
SHAFT COUPLER, JGB37-520
COUPLING BRACKET, GEARED BODY TO DC MOTOR, JGB37-520
PLASTIC COVER, DC MOTOR, JGB37-520
CONNECTION, DC MOTOR, JGB37-520 x 2
pan cross head_am_B18.6.7M - M2 x 0.4 x 25 Type I Cross Recessed PHMS --25N x 3

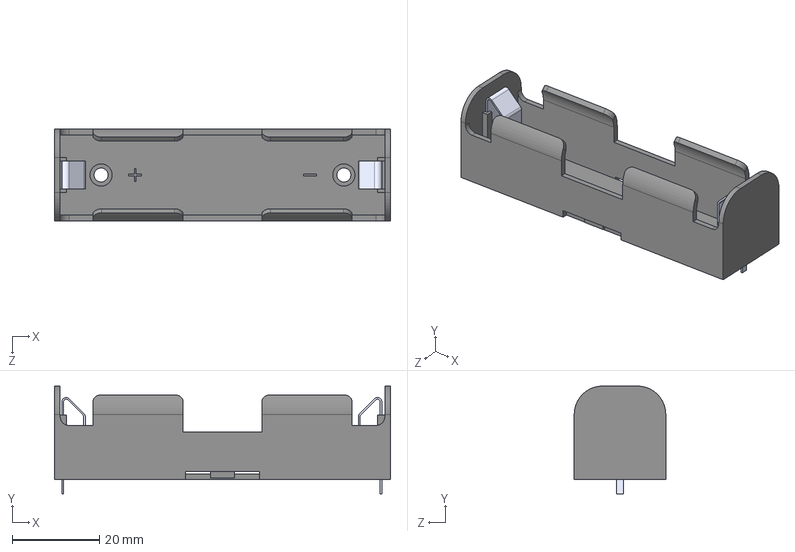
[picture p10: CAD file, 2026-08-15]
hardware/cad/models/BK-18650-PC2--3DModel-STEP-269445.STEP
77.0 x 24.7 x 21.0 mm

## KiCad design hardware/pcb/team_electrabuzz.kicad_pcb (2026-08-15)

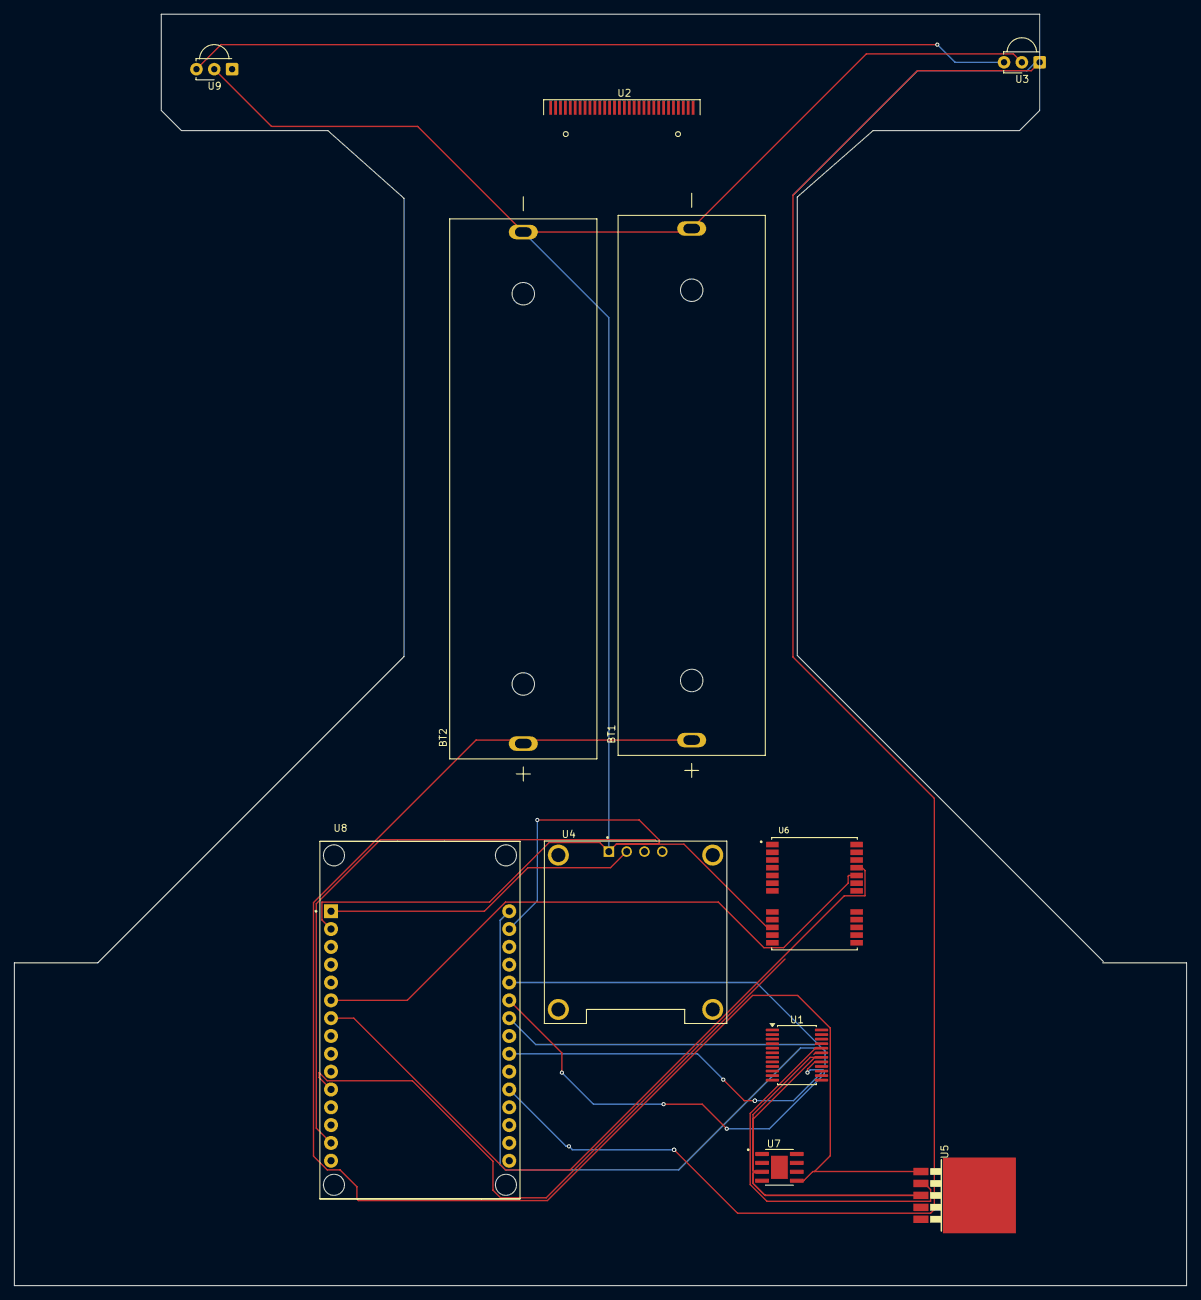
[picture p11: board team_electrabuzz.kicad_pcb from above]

Board: 2 copper layers, 167.1 x 181.2 mm, 11 parts (0 on the bottom side), 20 nets.

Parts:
BT1, BT2: BK-18650-PC2; BAT_BK-18650-PC2
U1: TB6612FNG; SSOP-24_5.3x8.2mm_P0.65mm
U2: ESP32-CAM; OLED-128O064D
U3, U9: TSSP58038; Vishay_MINICAST-3Pin
U4: DM-OLED096-636; MODULE_DM-OLED096-636
U5: LM2596; TO263-5
U6: NEO-6M-GPS; XCVR_NEO-6M-GPS
U7: TP4056; SOP127P600X175-9N
U8: ESP32-DEVKIT-V1; MODULE_ESP32_DEVKIT_V1

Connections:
3.3v: U1.19 (STBY), U3.3 (Vs), U4.2 (VCC_IN), U6.23 (VCC), U8.1 (3V3), U9.3 (Vs)
GND: BT1.-, BT2.-, U1.18 (GND), U3.2 (GND), U4.1 (GND), U5.3 (GND), U6.10 (GND), U6.12 (GND), U6.13 (GND), U6.24 (GND), U7.3 (GND), U8.2 (GND), U8.29 (GND), U9.2 (GND)
unnamed: U1.1 (AO1), U1.2 (AO1)
unnamed: U1.5 (AO2), U1.6 (AO2)
unnamed: U1.11 (BO1), U1.12 (BO1)
unnamed: U1.7 (BO2), U1.8 (BO2)
unnamed: U1.21 (AIN1), U8.23 (D25)
unnamed: U1.22 (AIN2), U8.24 (D26)
unnamed: U1.17 (BIN1), U8.25 (D27)
unnamed: U1.16 (BIN2), U8.26 (D14)
unnamed: U1.23 (PWMA), U8.21 (D32)
unnamed: U1.15 (PWMB), U8.22 (D33)
unnamed: U1.20 (VCC), U5.2 (OUT), U8.30 (VIN)
unnamed: U3.1 (OUT), U8.20 (D35)
unnamed: U4.3 (SCL), U8.14 (D22)
unnamed: U4.4 (SDA), U8.11 (D21)
unnamed: BT1.+, BT2.+, U5.1 (VIN), U7.5 (BAT)
unnamed: U6.21 (RXD1), U8.7 (TX2)
unnamed: U6.20 (TXD1), U8.6 (RX2)
unnamed: U8.19 (D34), U9.1 (OUT)

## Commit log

2026-04-11 Rename 'Buck Converter' to 'Buck Module' in README
2026-04-11 Rename WhatsApp Image 2026-04-11 at 2.39.57 PM.jpeg to Schematic.jpeg
2026-08-15 refactor: restructure repository for portfolio presentation
    [BK-18650-PC2--3DModel-STEP-269445.STEP, BK.STEP, DM-OLED096-636--3DModel-STEP-56544.STEP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]
